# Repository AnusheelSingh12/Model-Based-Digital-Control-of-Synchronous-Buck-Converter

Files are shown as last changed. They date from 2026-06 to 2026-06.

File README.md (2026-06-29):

# Model-Based Design and HIL Deployment of a Cascade Digital Controller for a Synchronous Buck Converter on TI C2000 DSP

## Summer Research Internship

**Institution:** Indian Institute of Technology Guwahati

**Duration:** May 2026 – July 2026

---

# Overview

This repository documents my Summer Research Internship carried out at the Department of Electronics and Electrical Engineering, Indian Institute of Technology Guwahati.

The internship focused on the complete workflow involved in designing, simulating, implementing, and validating a digitally controlled synchronous buck converter using the Texas Instruments C2000 real-time digital signal processor platform.

Unlike repositories that present only the final implementation, this repository documents the complete engineering process, beginning with mathematical modeling and simulation, progressing through controller design, embedded firmware development, peripheral configuration, laboratory validation, and finally hardware deployment.

The project combines concepts from:

* Power Electronics
* Control Systems
* Embedded Systems
* Digital Signal Processing
* MATLAB & Simulink
* Simscape Electrical
* Real-Time Embedded Programming
* Hardware-in-the-Loop Development

---

# Project Objectives

The primary objectives of the internship were:

* Develop a high-fidelity digital twin of a synchronous buck converter.
* Design a cascaded digital controller consisting of outer voltage and inner current control loops.
* Learn the Texas Instruments C2000 development ecosystem.
* Implement embedded firmware using Code Composer Studio.
* Configure and validate DSP peripherals including GPIO, Timers, PWM, Interrupts, and ADC.
* Validate controller performance using laboratory instruments.
* Document the complete engineering workflow.

---

# Engineering Workflow

```text
Problem Definition
        │
        ▼
MATLAB Fundamentals
        │
        ▼
Simulink Fundamentals
        │
        ▼
Simscape Electrical
        │
        ▼
Digital Twin Development
        │
        ▼
Cascade PI Controller Design
        │
        ▼
Closed Loop Simulation
        │
        ▼
TI C2000 DSP Learning
        │
        ▼
GPIO
Interrupts
CPU Timers
PWM
ADC
        │
        ▼
Hardware Validation
        │
        ▼
Final System Integration
```

---

# Repository Structure

```text
IITG-DSP-Buck-Converter-Control/

├── 01_Internship_Overview/
│
├── 02_MATLAB_and_Simulink/
│
├── 03_Digital_Twin/
│
├── 04_Cascade_Controller/
│
├── 05_TI_C2000_DSP/
│   ├── GPIO/
│   ├── Interrupts/
│   ├── CPU_Timers/
│   ├── ePWM/
│   ├── ADC/
│
├── 06_Hardware_Setup/
│   ├── LaunchXL_F28379D/
│   ├── Oscilloscope/
│   ├── Function_Generator/
│
├── 07_Firmware/
│
├── 08_Simulation_Results/
│
├── 09_Final_Report/
│
├── Images/
│
├── Videos/
│
└── README.md
```

---

# Project Phases

## Phase 1 — Digital Twin Development

The first stage of the project focused on constructing a high-fidelity Simscape Electrical model of the synchronous buck converter.

Topics include:

* Converter topology
* MOSFET modelling
* Passive component modelling
* PWM generation
* Open-loop validation
* Converter analysis
* Duty-cycle experiments

---

## Phase 2 — Cascade Digital Controller

The second stage involved designing a cascaded digital controller.

Topics include:

* Voltage control loop
* Current control loop
* PI controller design
* Closed-loop regulation
* Controller tuning
* Performance analysis

---

## Phase 3 — TI C2000 DSP Development

The third stage focused on learning and implementing embedded firmware using the Texas Instruments C2000 platform.

Topics include:

* Code Composer Studio
* Project configuration
* GPIO
* Interrupts
* CPU Timers
* Enhanced PWM
* ADC
* Debugging
* Flash programming

---

## Phase 4 — Hardware Validation

The final stage focuses on validating both the firmware and control algorithms using laboratory equipment.

Topics include:

* Oscilloscope measurements
* Function generator experiments
* PWM verification
* ADC verification
* Peripheral testing
* System integration

---

# Software and Development Tools

MATLAB

Simulink

Simscape Electrical

Code Composer Studio

C2000Ware

Texas Instruments C2000 Driver Library

---

# Hardware Platform

Texas Instruments LaunchXL-F28379D

Texas Instruments C2000 DSP

Rigol Digital Oscilloscope

Function Generator

Host Computer

---

# Skills Developed

Throughout this internship I gained practical experience in:

* Model-Based Design
* Power Electronics
* Control Systems
* Digital Signal Processing
* MATLAB Programming
* Simulink Modelling
* Simscape Electrical
* Embedded C Programming
* TI C2000 Development
* Code Composer Studio
* GPIO Configuration
* Interrupt Programming
* CPU Timers
* PWM Generation
* ADC Configuration
* Oscilloscope Measurements
* Function Generator Operation
* Hardware Debugging
* Engineering Documentation

---

# Repository Navigation

| Section | Description |
| --- | --- |
| Internship Overview | Internship objectives, timeline, and research scope |
| MATLAB and Simulink | Learning material and simulation fundamentals |
| Digital Twin | Simscape converter modelling |
| Cascade Controller  | Controller design and closed-loop simulation |
| TI C2000 DSP | Embedded firmware development |
| Hardware Setup | Laboratory setup and instrumentation |
| Firmware | Embedded source code |
| Simulation Results  | Waveforms and experimental validation |
| Final Report | Internship report and documentation |

---

# Current Status

The repository is actively maintained and will continue to be updated throughout the internship.

Future updates include:

* Complete firmware
* Hardware validation
* Oscilloscope measurements
* ADC experiments
* Closed-loop implementation
* Final internship report
* Demonstration videos

---

# Acknowledgements

I would like to express my sincere gratitude to my internship supervisor, research mentors, and the School of Electronics and Electrical Engineering at the Indian Institute of Technology Guwahati for providing the opportunity to work on this project and gain practical experience in model-based design, embedded control systems, and real-time digital signal processing.

---

# Author

Anusheel Singh

Electronics and Communication Engineering

Areas of Interest

* Embedded Systems
* Digital Control Systems
* Power Electronics
* DSP
* Hardware Integration
* Robotics
* Automotive Electronics

---

This repository is intended to serve as a complete technical record of my internship, documenting both the engineering process and the final implementation.

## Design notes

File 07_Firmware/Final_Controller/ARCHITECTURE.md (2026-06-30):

# Synchronous Buck Converter — Firmware Architecture Guide
## TI LaunchXL-F28379D | Cascaded PI Control | 100kHz

---

## 1. File Structure

```
buck_converter/
├── src/
│   ├── main.c          → System init, startup sequence
│   ├── epwm.c          → PWM generation, duty cycle update
│   ├── adc.c           → ADC configuration, scaling constants
│   ├── controller.c    → PI controller math, anti-windup
│   └── interrupts.c    → ADC ISR, complete control loop
├── include/
│   ├── epwm.h          → PWM defines, function prototypes
│   ├── adc.h           → ADC channel assigns, scaling, globals
│   ├── controller.h    → PI struct, gains, prototypes
│   └── interrupts.h    → ISR prototype
└── ARCHITECTURE.md     → This file
```

---

## 2. Control Flow

```
EPWM1 Counter = 0 (every 10us)
        ↓
SOCA Trigger → ADCA + ADCB sample simultaneously
        ↓
ADC Conversion (~300ns)
        ↓
ADCINT1 fires → ADC_ISR enters
        ↓
Read Vout raw, Iout raw
        ↓
Scale to V and A
        ↓
Voltage PI: error_v = Vref - Vout → Iref
        ↓
Current PI: error_i = Iref - Iout → duty
        ↓
EPWM_setDutyCycle(duty) → CMPA shadow register
        ↓
Clear ADCINT1 flag + PIE ACK Group 1
        ↓
ISR exits → CPU idle until next cycle
        ↓
Next counter zero: shadow CMPA → active CMPA
```

---

## 3. Simulink to Firmware Mapping

| Simulink Block | Firmware Location |
|---|---|
| ADC (Vout channel) | `adc.c` ADCA SOC0 |
| ADC (Iout channel) | `adc.c` ADCB SOC0 |
| ADC Scaling gain | `g_vOut = raw * VOLTAGE_SCALE` |
| Voltage reference (12V) | `g_vref = VREF` in controller.h|
| Voltage PI block | `PI_update(&voltagePI, ...)` |
| Current PI block | `PI_update(&currentPI, ...)` |
| Anti-windup saturation | Integrator clamp in PI_update()|
| Duty cycle saturation | EPWM_setDutyCycle() clamp |
| PWM Generator | `epwm.c` EPWM1 AQ config |
| Sample Time (Ts = 10us) | EPWM SOCA trigger, 100kHz |

---

## 4. Key Register Reference

### ePWM Registers
| Register | Purpose | This Project |
|---|---|---|
| TBPRD | Sets switching frequency | 1000 → 100kHz |
| CMPA | Sets duty cycle | 50-950 (5%-95%) |
| TBCTL | Counter mode | Up-Down |
| AQCTLA | Output logic | HIGH up, LOW down |
| DBRED | Rising edge dead time | 20 counts = 100ns |
| DBFED | Falling edge dead time | 20 counts = 100ns |
| ETSEL | ADC trigger source | Counter zero |
| ETPS | Trigger prescale | Every cycle |

### ADC Registers
| Register | Purpose | This Project |
|---|---|---|
| ADCCTL2  | Clock prescaler | /4 = 50MHz |
| ADCSOC0CTL | Channel, trigger, window | ADCIN0, EPWM1SOCA, 15 cycles |
| ADCINTSEL | Interrupt source | SOC0 EOC |
| ADCRESULT0 | Conversion result | 0-4095 counts |

---

## 5. Watch Window Variables (Debug)

Add these to Expressions window in CCS:

| Variable | Description | Expected at 12V/1A |
|---|---|---|
| `g_vOut` | Measured output voltage (V) | ~12.0 |
| `g_iOut` | Measured output current (A) | ~1.0 |
| `g_vref` | Voltage reference (V) | 12.0 |
| `g_iref` | Current reference from Vloop | ~1.0 |
| `g_duty` | Duty cycle (normalized) | ~0.5 |
| `g_error_v` | Voltage error (V) | ~0.0 at steady state|
| `g_error_i` | Current error (A) | ~0.0 at steady state|
| `g_adcVoutRaw`| Raw ADC count (debug) | ~1858 |
| `g_adcIoutRaw`| Raw ADC count (debug) | ~varies with sensor|

---

## 6. PI Gain Tuning Procedure

### Step 1: Start Open Loop
Comment out the PI calls in interrupts.c and set fixed duty:
```c
g_duty = 0.5f;  // Fixed 50% for testing
EPWM_setDutyCycle(g_duty);
```
Verify Vout ≈ 12V on scope. Verify ADC reads correct value.

### Step 2: Tune Current Loop First (Inner)
Re-enable current PI only. Set Iref manually:
```c
g_iref = 1.0f;  // 1A reference, fixed
g_duty = PI_update(&currentPI, g_iref, g_iout);
```
Increase CURRENT_KP until current waveform oscillates. Back off 50%.
Then increase CURRENT_KI until steady state error is zero.

### Step 3: Tune Voltage Loop (Outer)
Re-enable both loops. Start with very small VOLTAGE_KP (0.01).
Increase until Vout responds quickly to step changes in Vref.
Add VOLTAGE_KI to eliminate steady-state error.

### Step 4: Verify on Scope
- CH1: EPWM1A (GPIO0) — 100kHz square wave
- CH2: Vout — steady 12V with small ripple
- CH3: Inductor current (if current probe available)

---

## 7. Expected Converter Parameters

```
Duty Cycle (D)    = Vout/Vin = 12/24 = 0.5 (50%)
Inductor Ripple   = Vin*D*(1-D) / (L*Fsw) = 24*0.5*0.5 / (50e-6*100e3) = 1.2A
Capacitor Ripple  = ΔIL / (8*C*Fsw) = 1.2 / (8*12.5e-6*100e3) = 120mV
Output Current    = Vout/Rload = 12/12 = 1A
```

These are your theoretical verification targets on the oscilloscope.

---

## 8. Hardware Connections

```
LaunchPad Pin    Signal         Connect To
─────────────────────────────────────────────
GPIO0 (J4 Pin2)  EPWM1A HS PWM  Gate driver IN+ (High Side)
GPIO1 (J4 Pin4)  EPWM1B LS PWM  Gate driver IN- (Low Side)
ADCINA0          Vout feedback  Resistor divider output
ADCINB0          Iout feedback  Current sensor output
GND              Ground         Shared GND with converter
3.3V             Vref           Current sensor supply
```

---

## 9. Safety Checklist Before Powering Converter

- [ ] Dead band verified on scope (no shoot-through)
- [ ] Duty cycle limits confirmed (5% min, 95% max)
- [ ] Current limit in voltage PI output (IREF_MAX = 2A)
- [ ] ADC scaling verified (g_vOut reads correct voltage)
- [ ] Both gate drive signals present on scope before connecting power
- [ ] Start with Vin = 5V, verify Vout, then increase to 24V

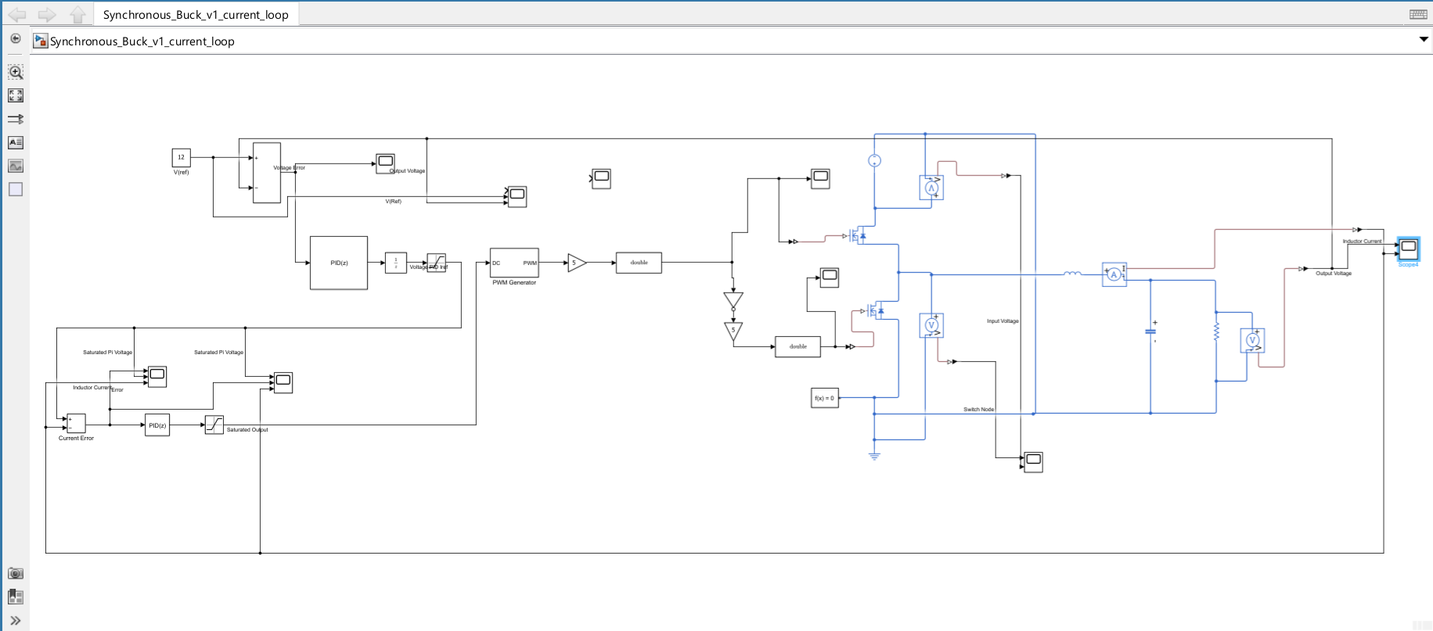
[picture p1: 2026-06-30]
02_MATLAB_Fundamentals/Images/Phase-2/Cascaded Control Architecture of Synchronous Buck Converter.png

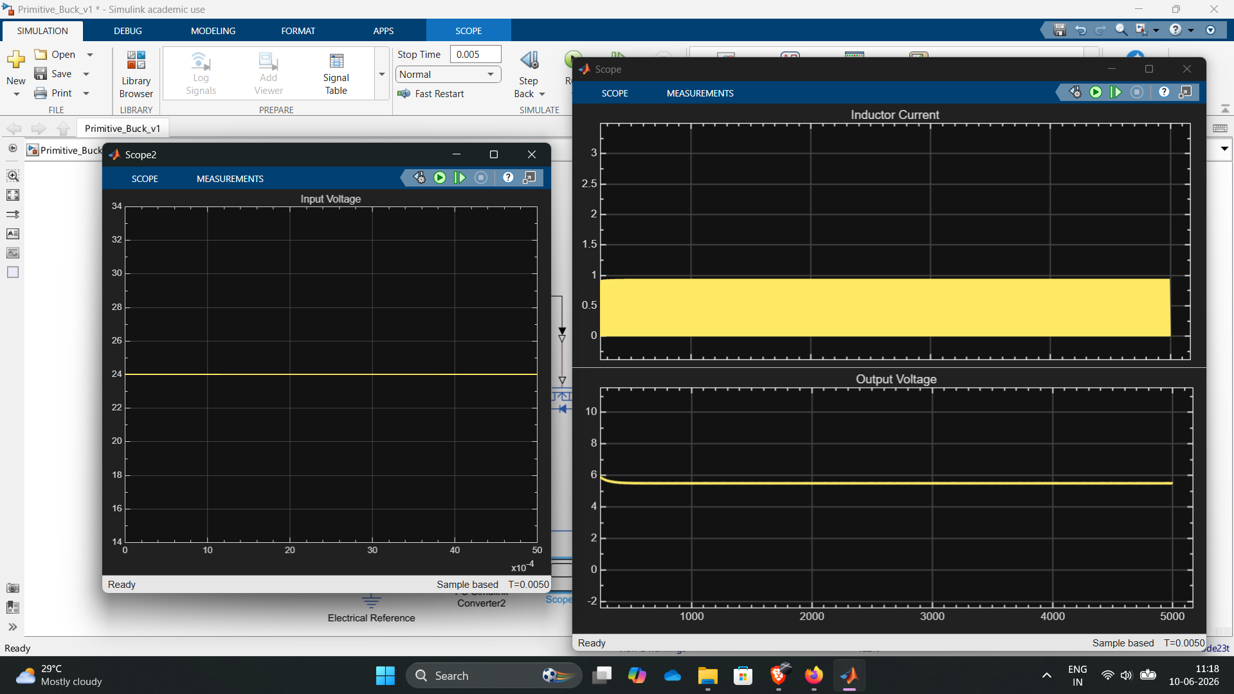
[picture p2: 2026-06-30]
03_Digital_Twin/Images/Primitive_Buck/25%_Duty_Cycle.png

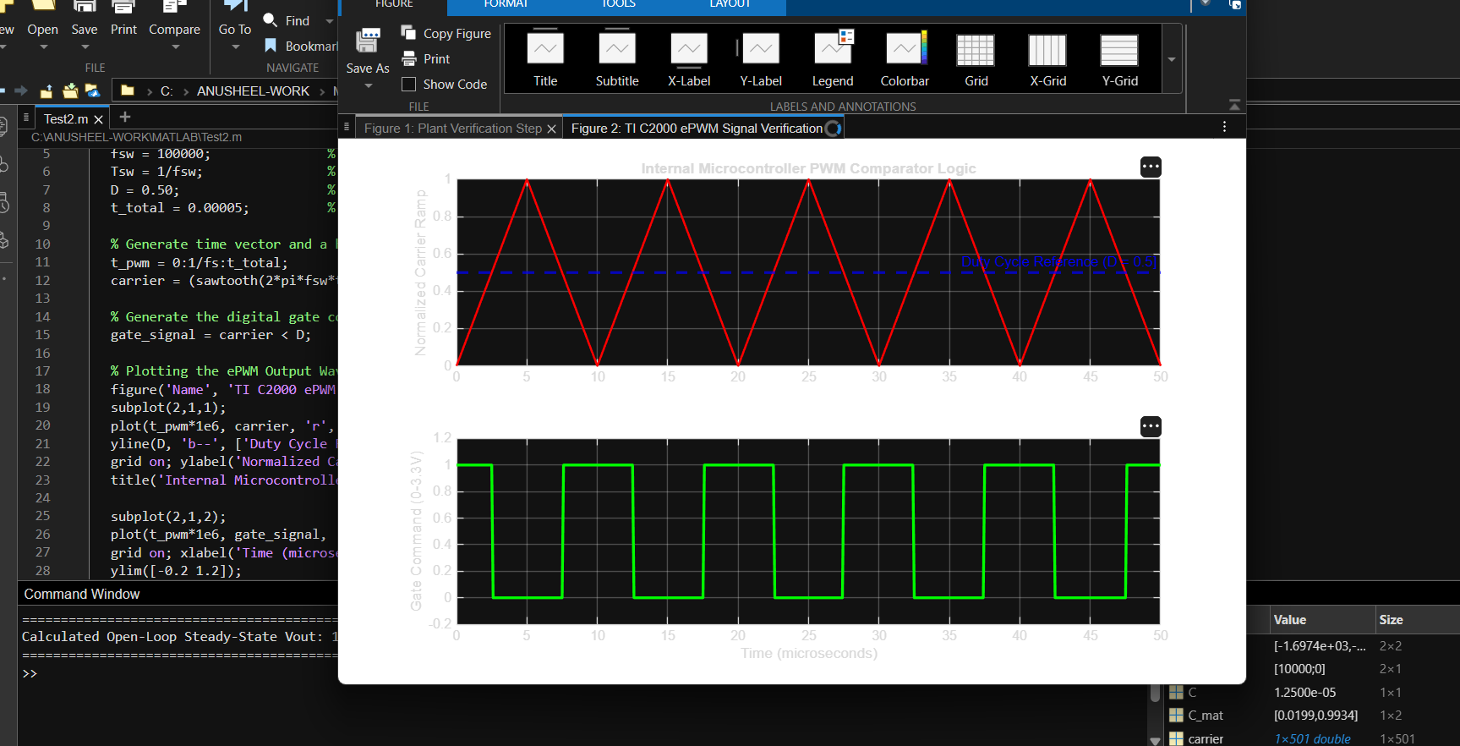
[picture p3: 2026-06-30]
02_MATLAB_Fundamentals/MATLAB/Images/Screenshot 2026-05-30 130607.png

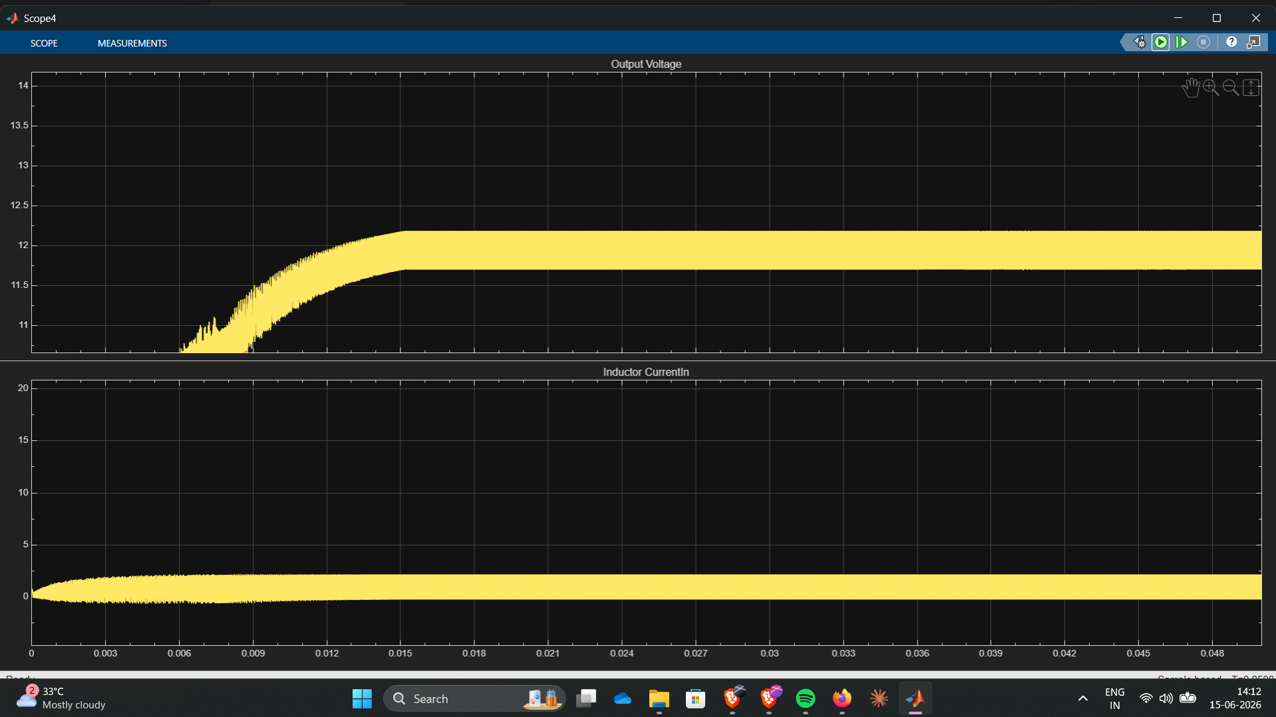
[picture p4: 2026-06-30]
02_MATLAB_Fundamentals/Images/Phase-2/Output_Voltage_Inductor_Current.png

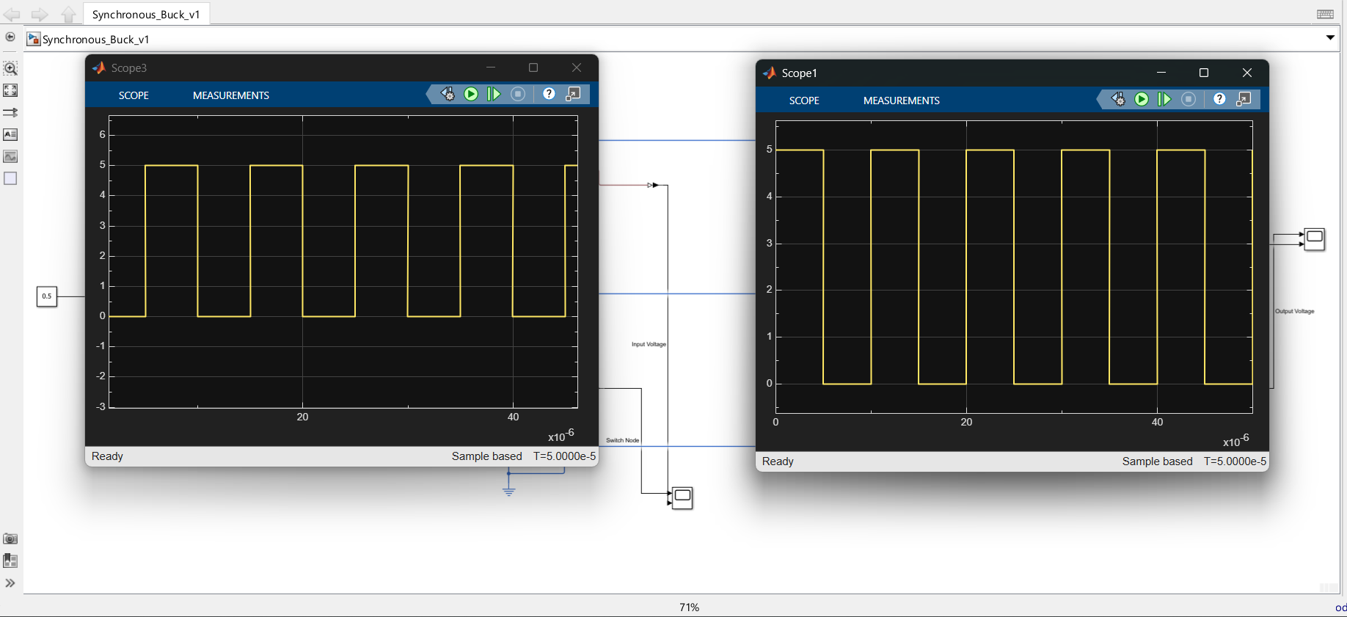
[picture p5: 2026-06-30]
03_Digital_Twin/Images/Synchronous_Buck/Input_PWM_Complementary_PWM.png

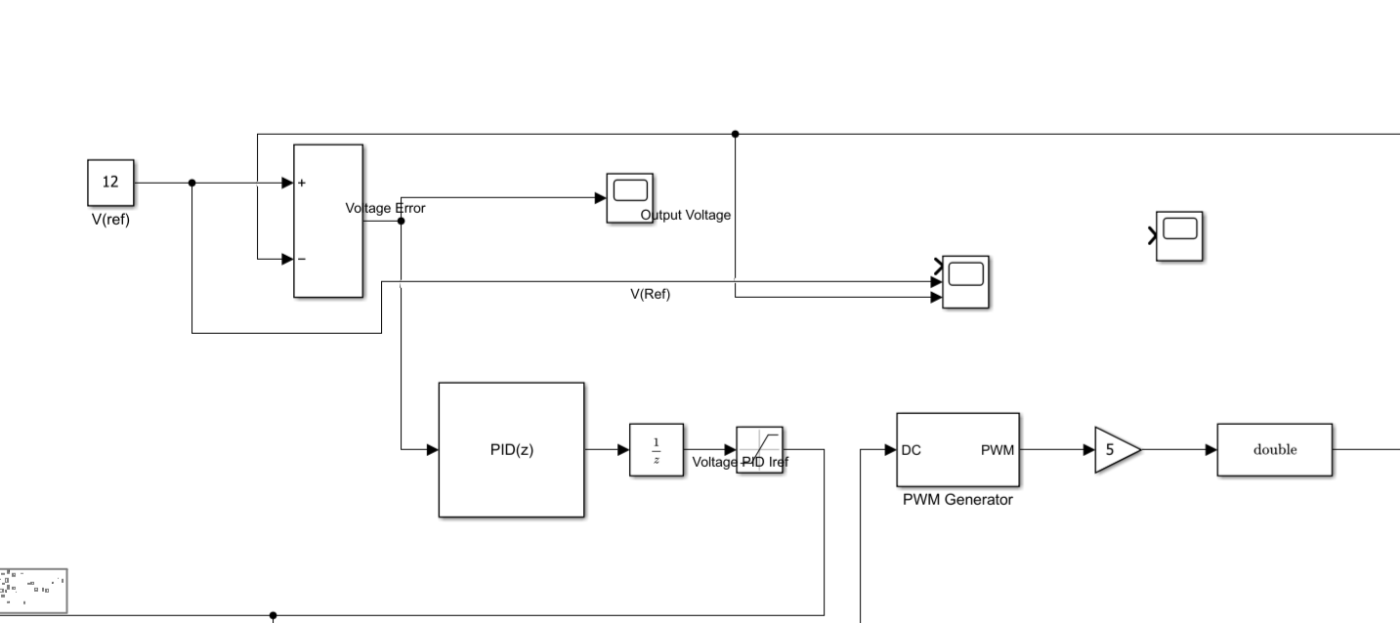
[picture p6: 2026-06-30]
02_MATLAB_Fundamentals/Images/Phase-2/Voltage_Loop.png

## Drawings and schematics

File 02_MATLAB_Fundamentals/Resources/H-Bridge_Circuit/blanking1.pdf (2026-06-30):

# 470pF ¹²kΩ

# IC10B 8 16 GND VCC IC10P

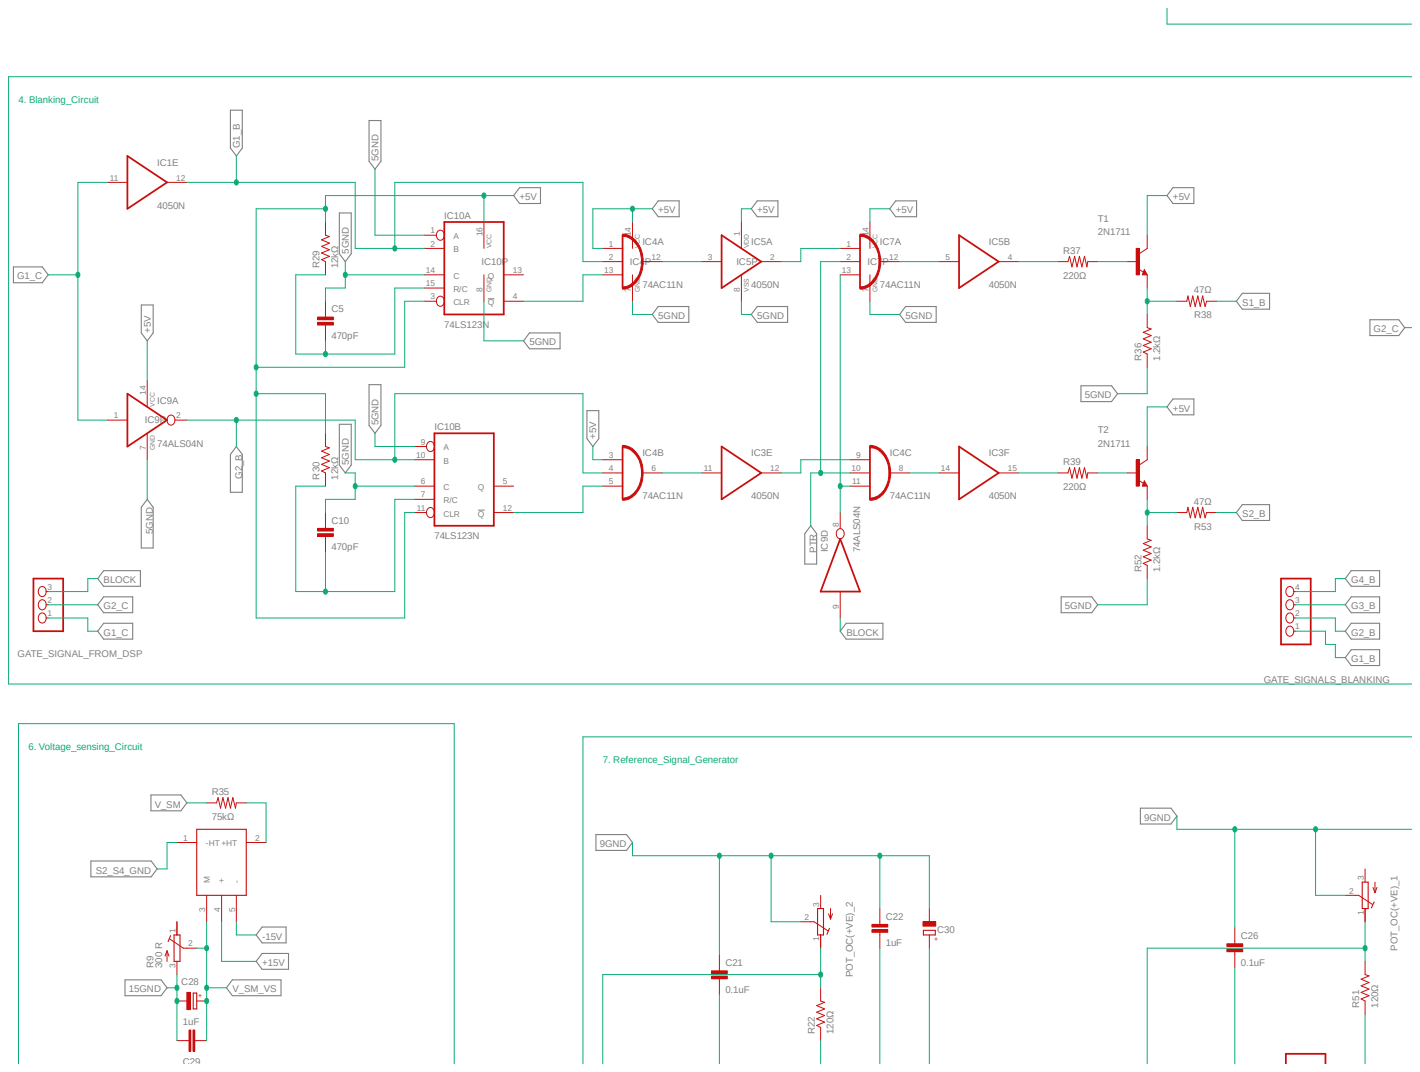
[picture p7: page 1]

IC7A 7 14 GND VCC IC7P 7 14 GND VCC IC4P

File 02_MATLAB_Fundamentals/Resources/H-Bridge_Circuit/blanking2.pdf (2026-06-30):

# 20-12-2025 12:21 C:\Users\eee\Desktop\SECL Materails\mmc_old.sch (Sheet: 1/1)

# 470pF ¹²kΩ

# IC12B 8 16 GND VCC IC12P

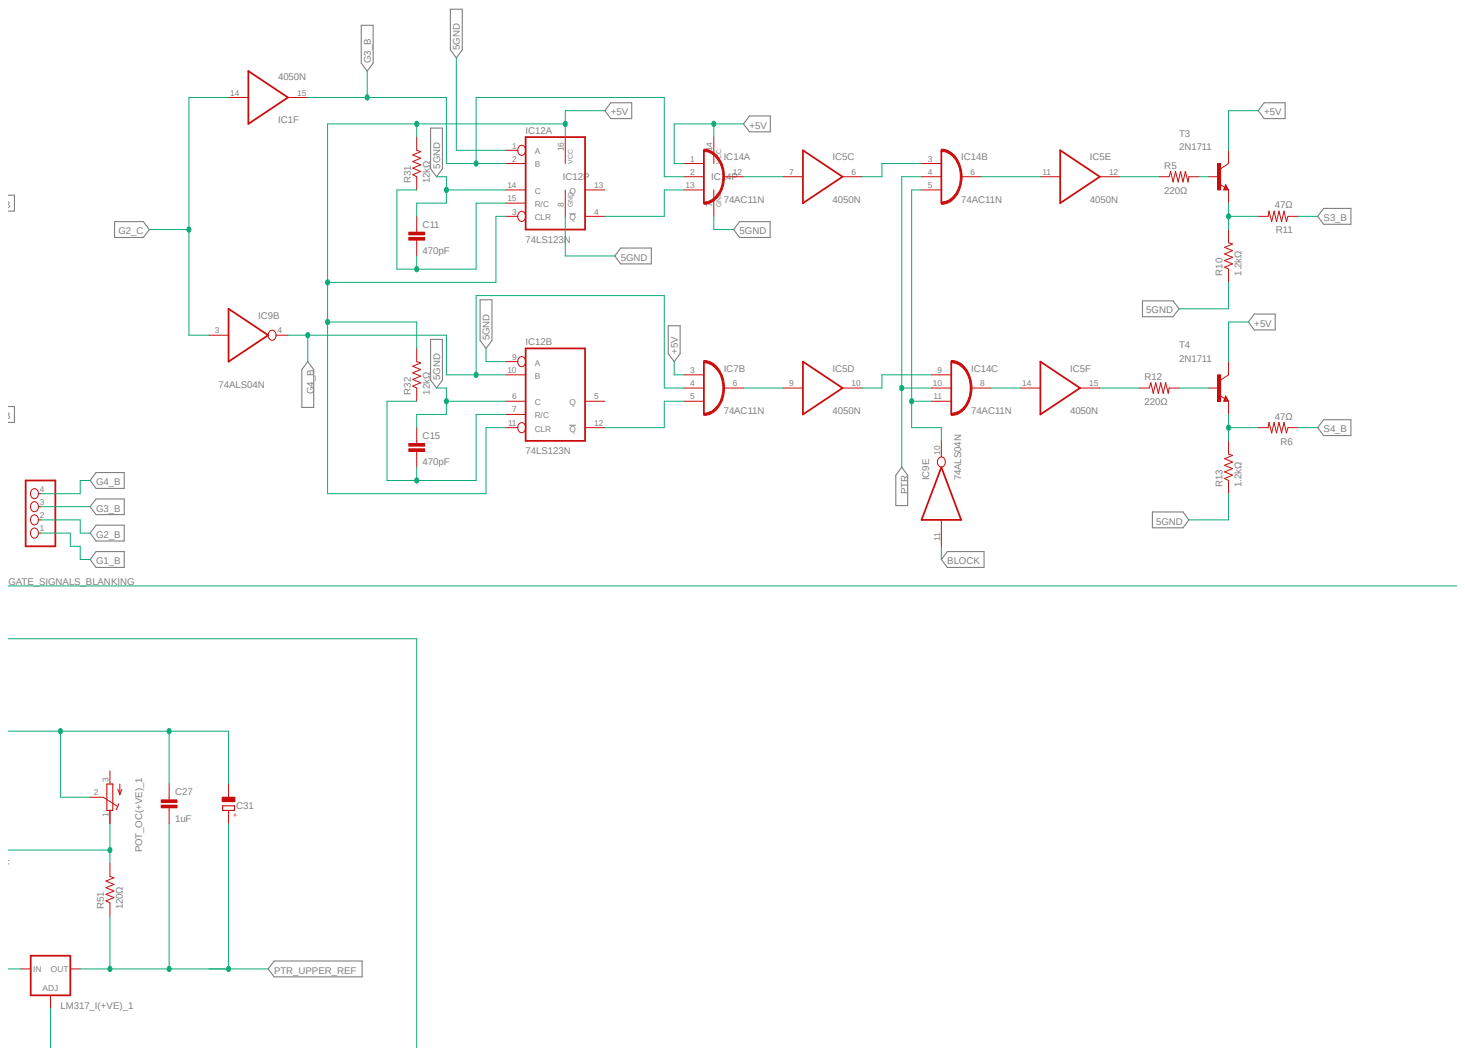
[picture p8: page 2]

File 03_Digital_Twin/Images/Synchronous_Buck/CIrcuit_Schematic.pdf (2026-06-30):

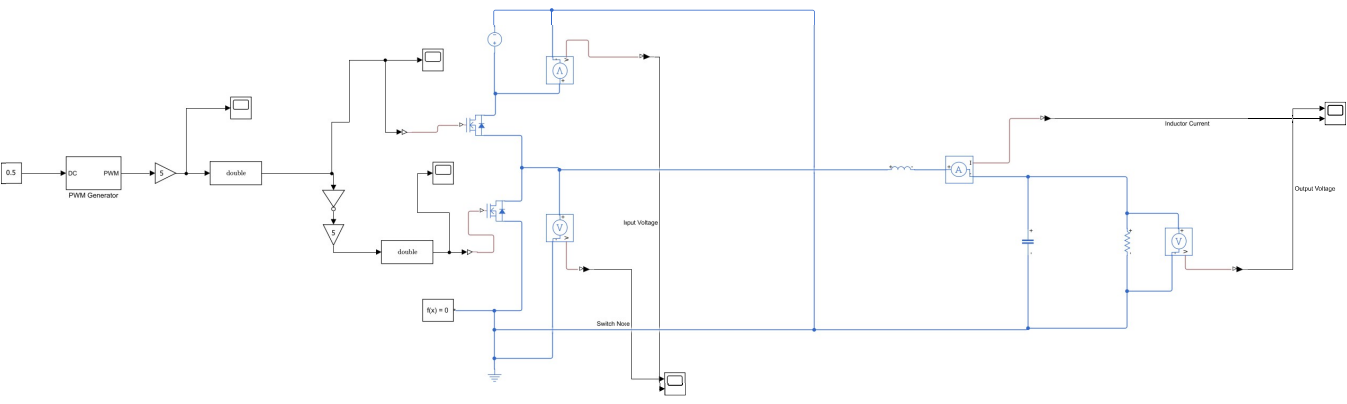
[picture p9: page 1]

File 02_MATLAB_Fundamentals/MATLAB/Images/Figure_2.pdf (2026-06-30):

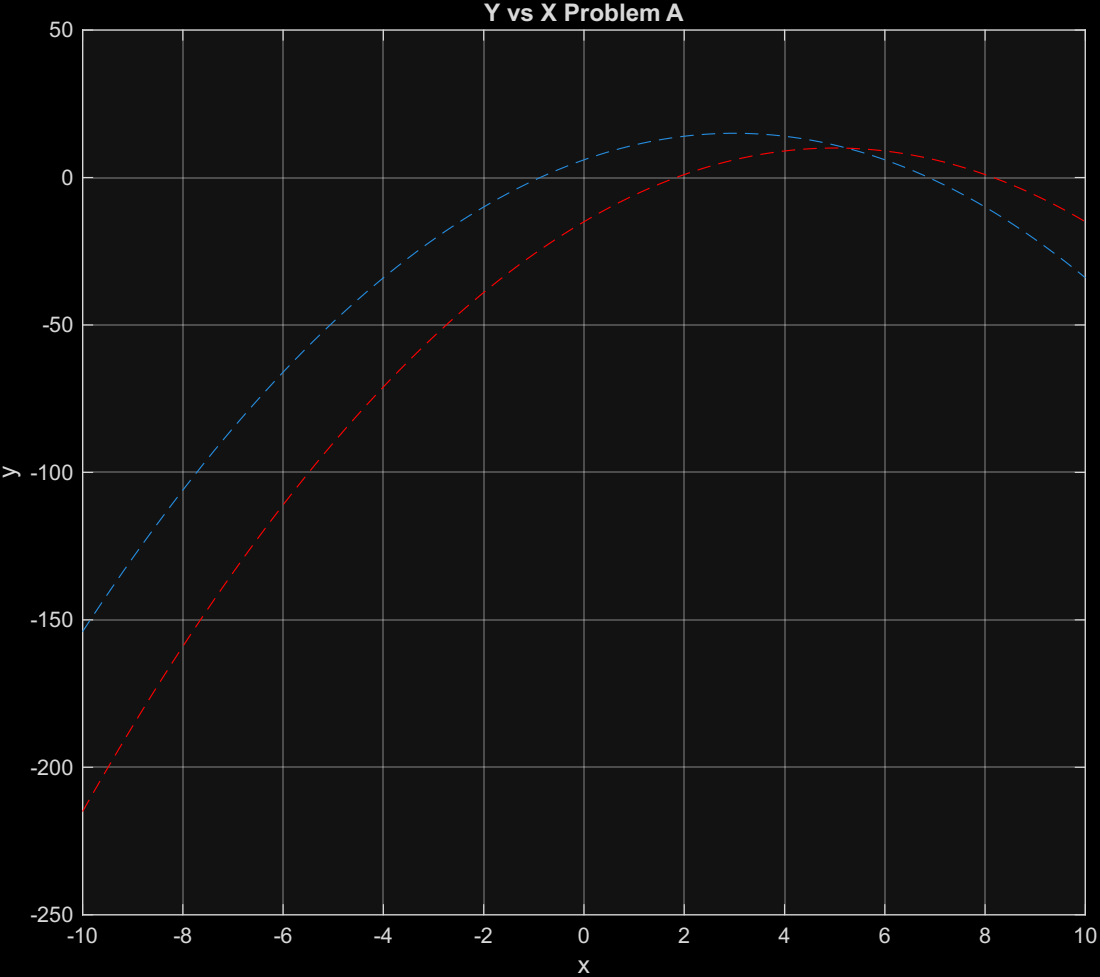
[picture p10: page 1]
Y vs X Problem A

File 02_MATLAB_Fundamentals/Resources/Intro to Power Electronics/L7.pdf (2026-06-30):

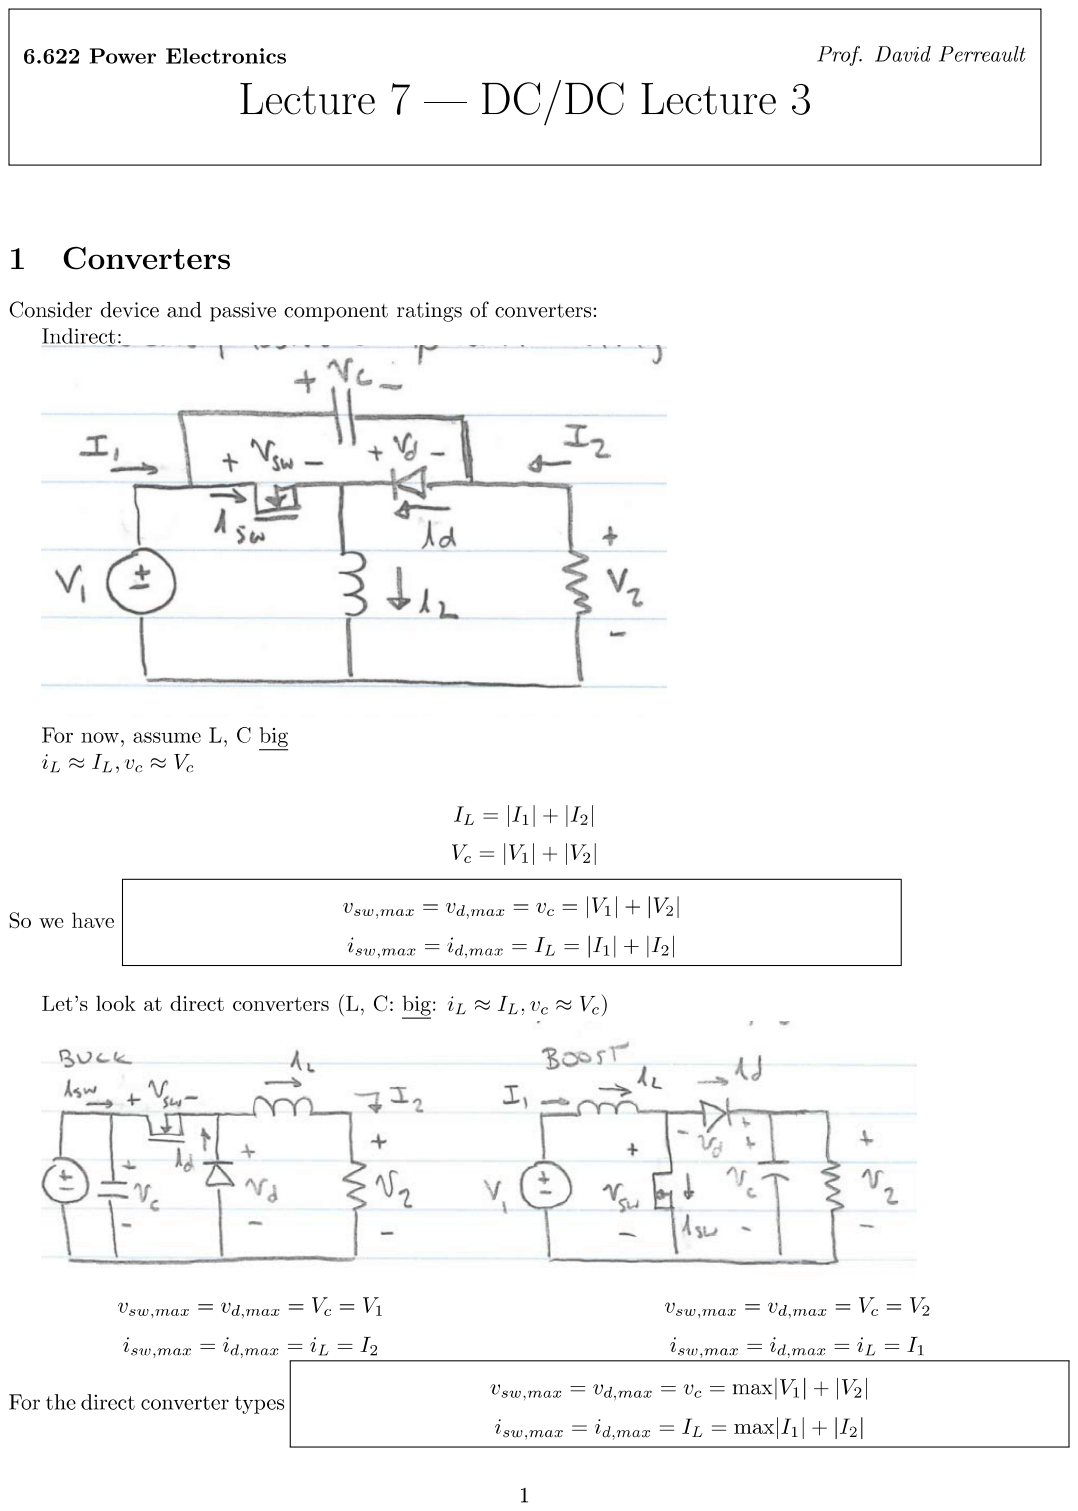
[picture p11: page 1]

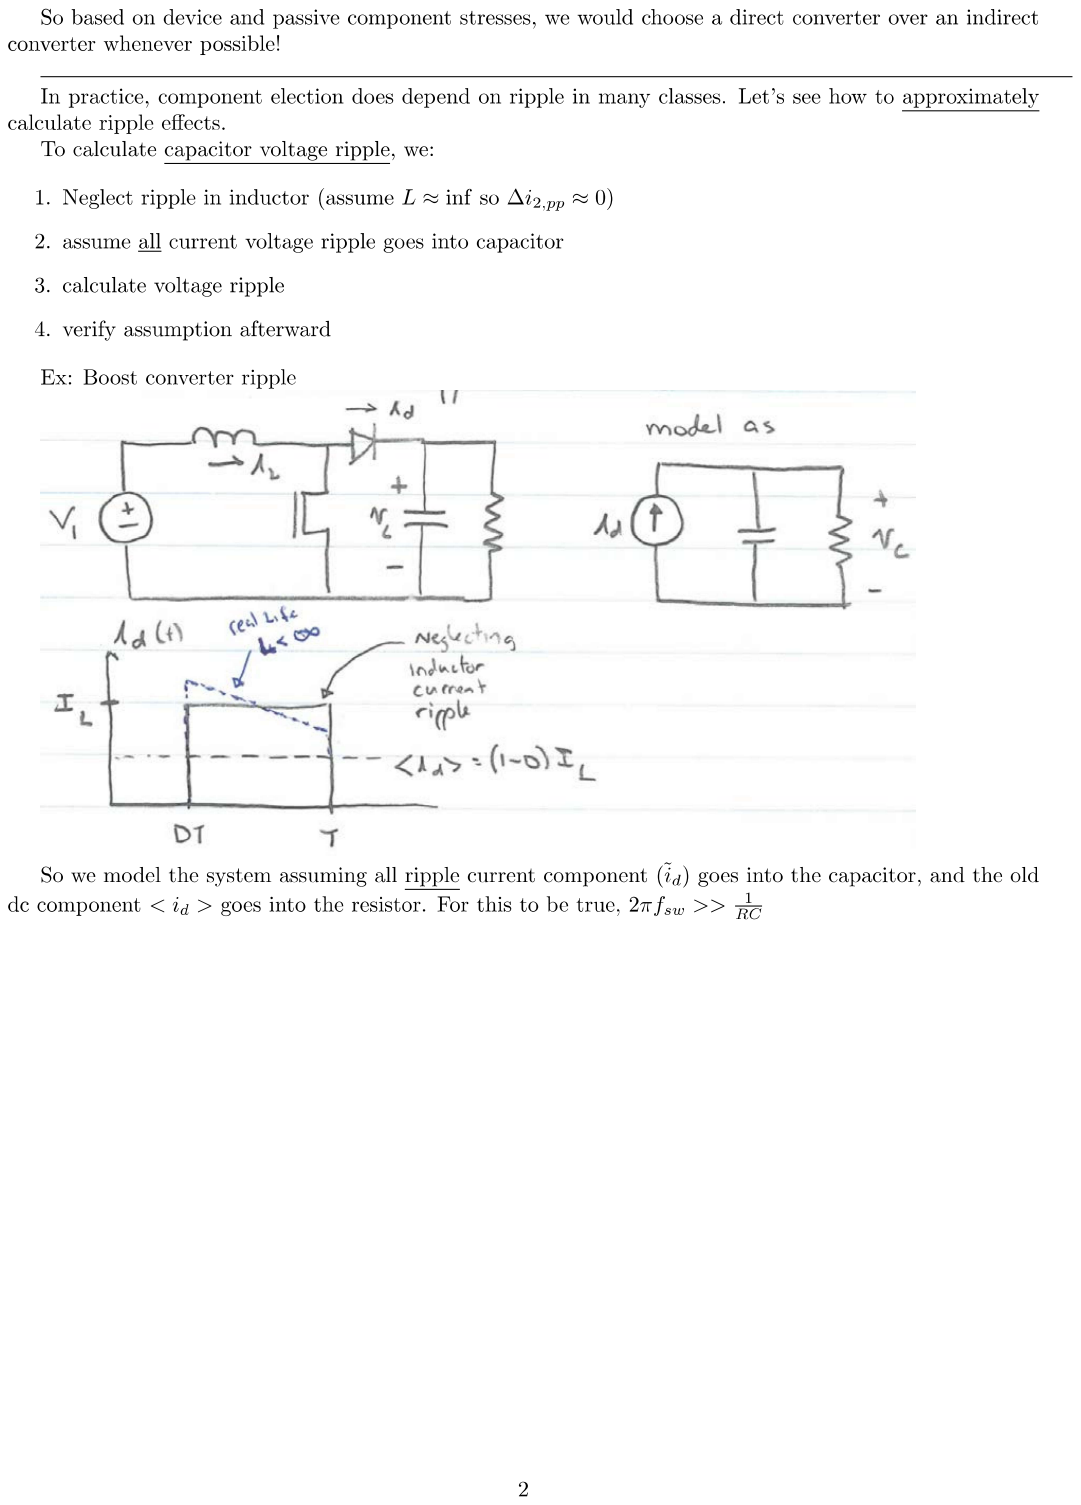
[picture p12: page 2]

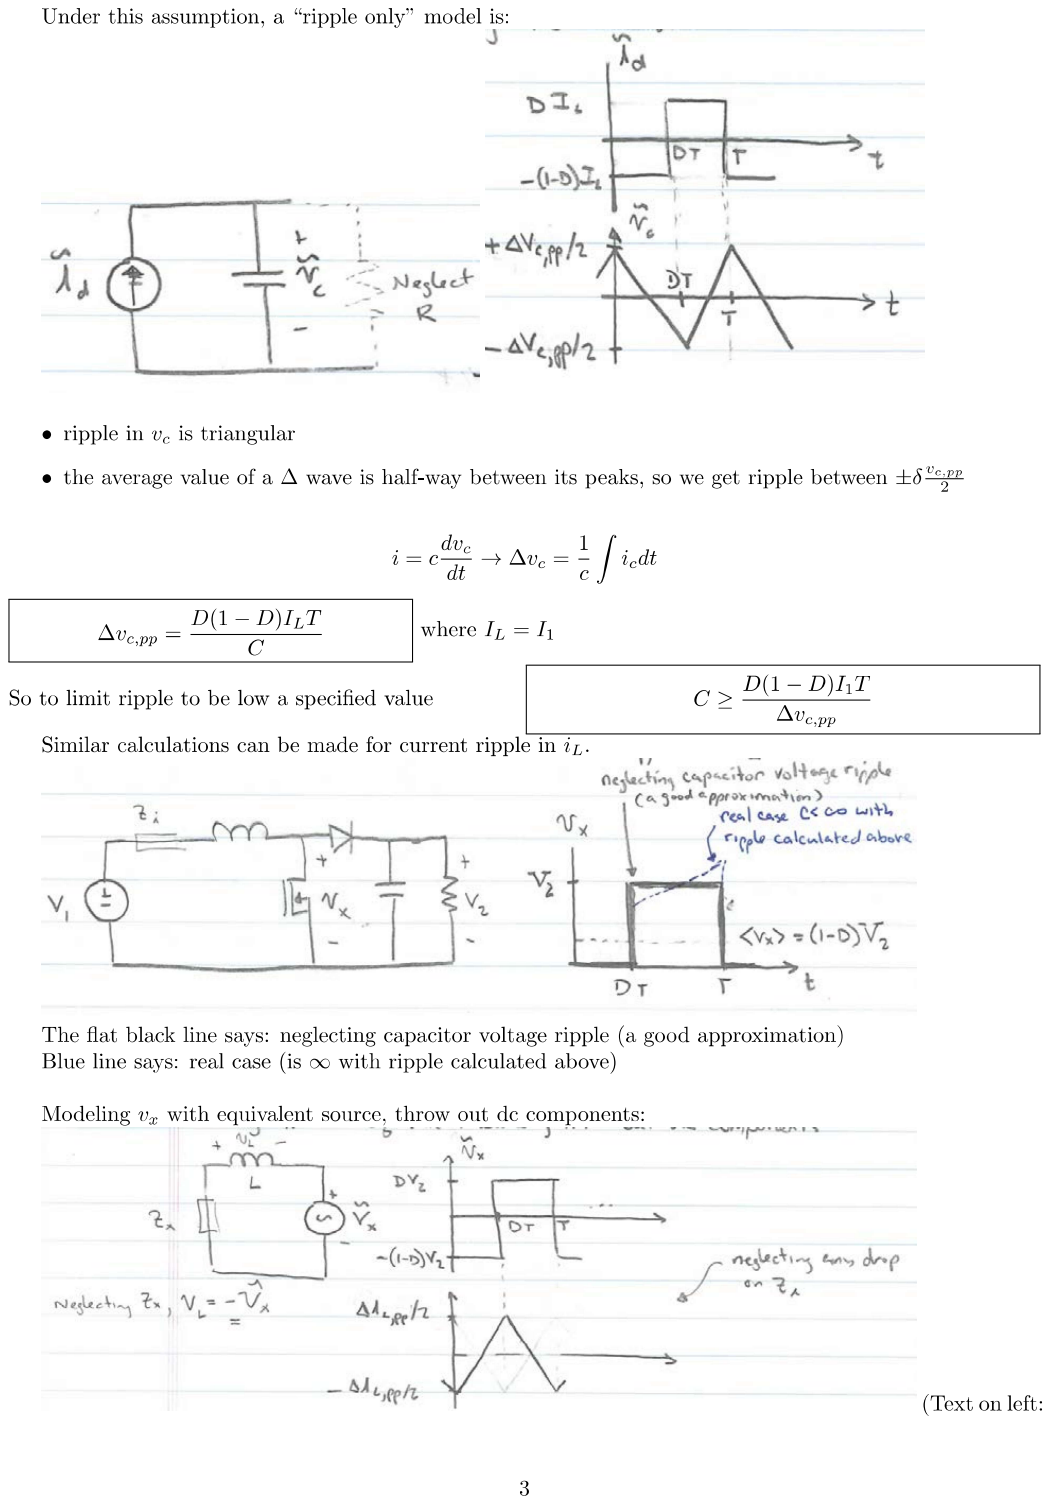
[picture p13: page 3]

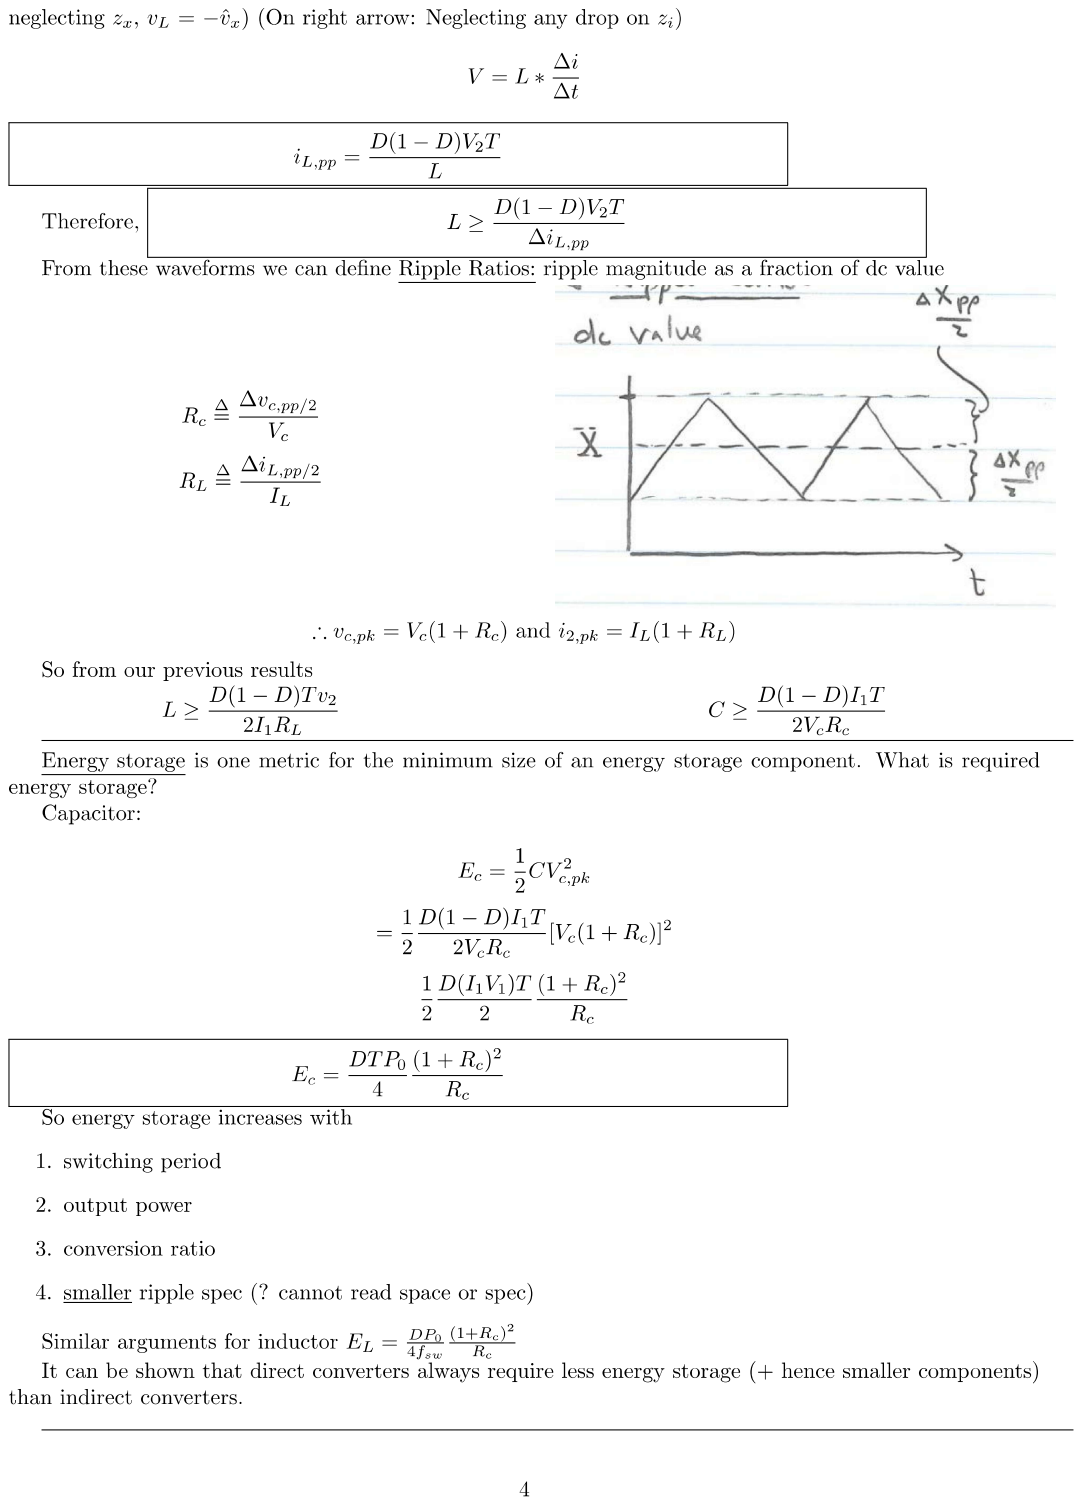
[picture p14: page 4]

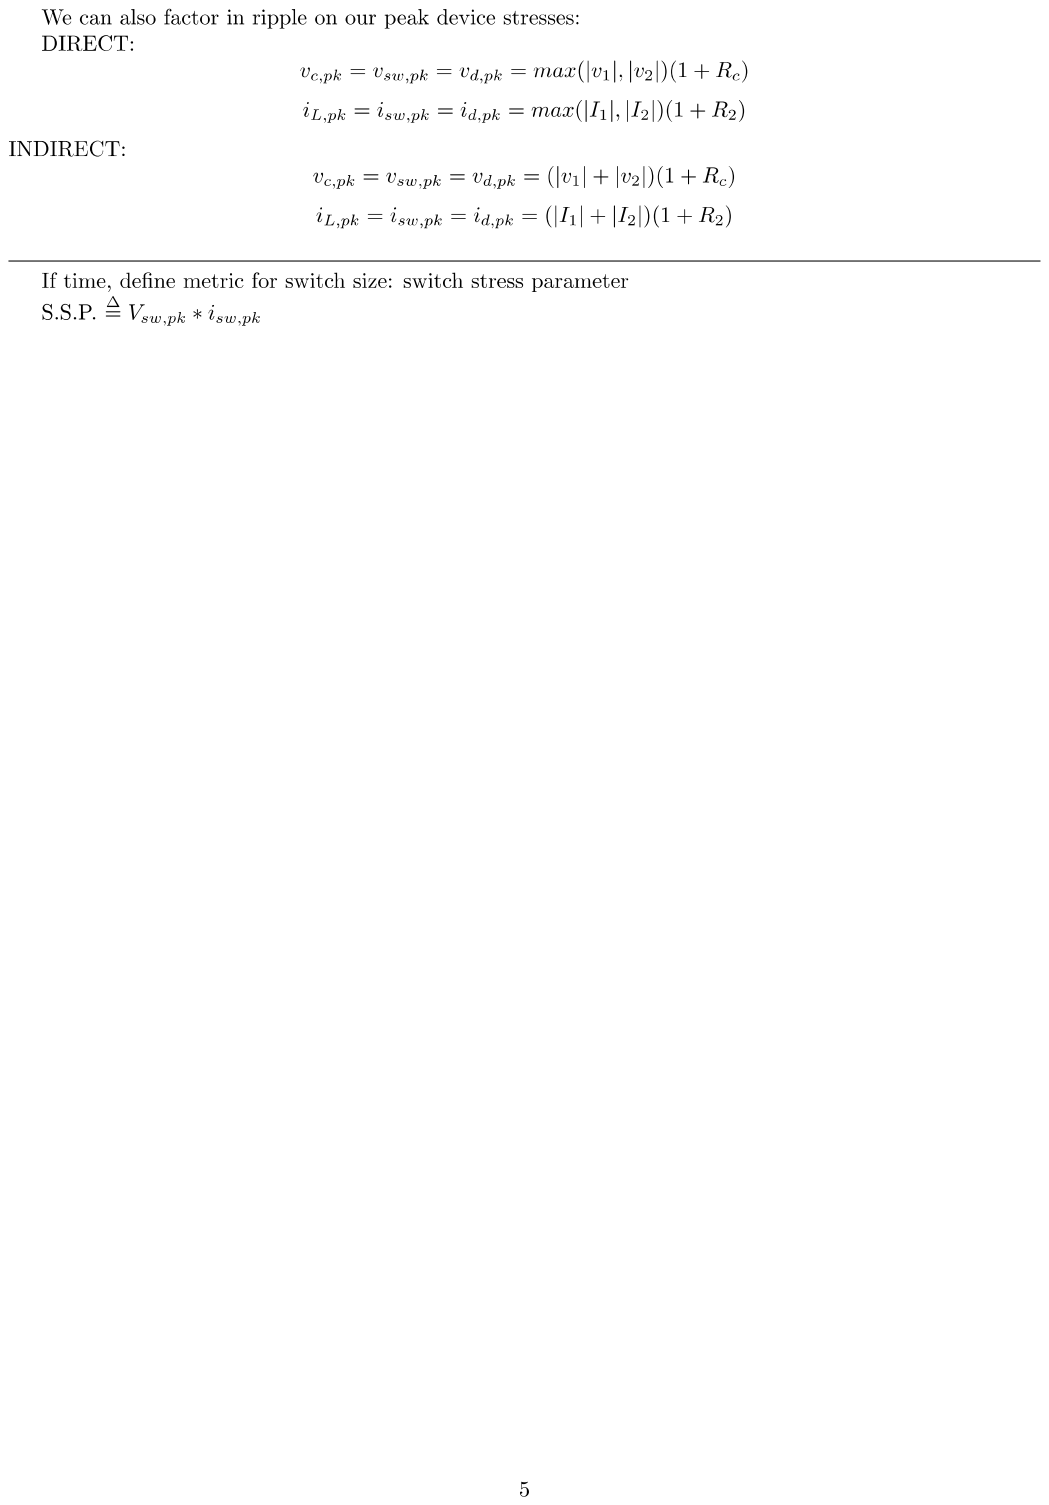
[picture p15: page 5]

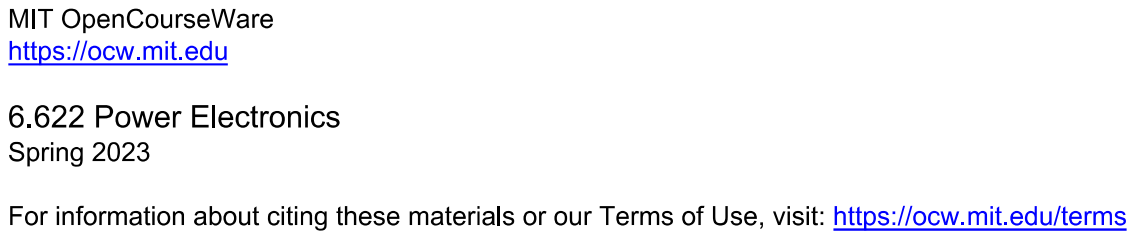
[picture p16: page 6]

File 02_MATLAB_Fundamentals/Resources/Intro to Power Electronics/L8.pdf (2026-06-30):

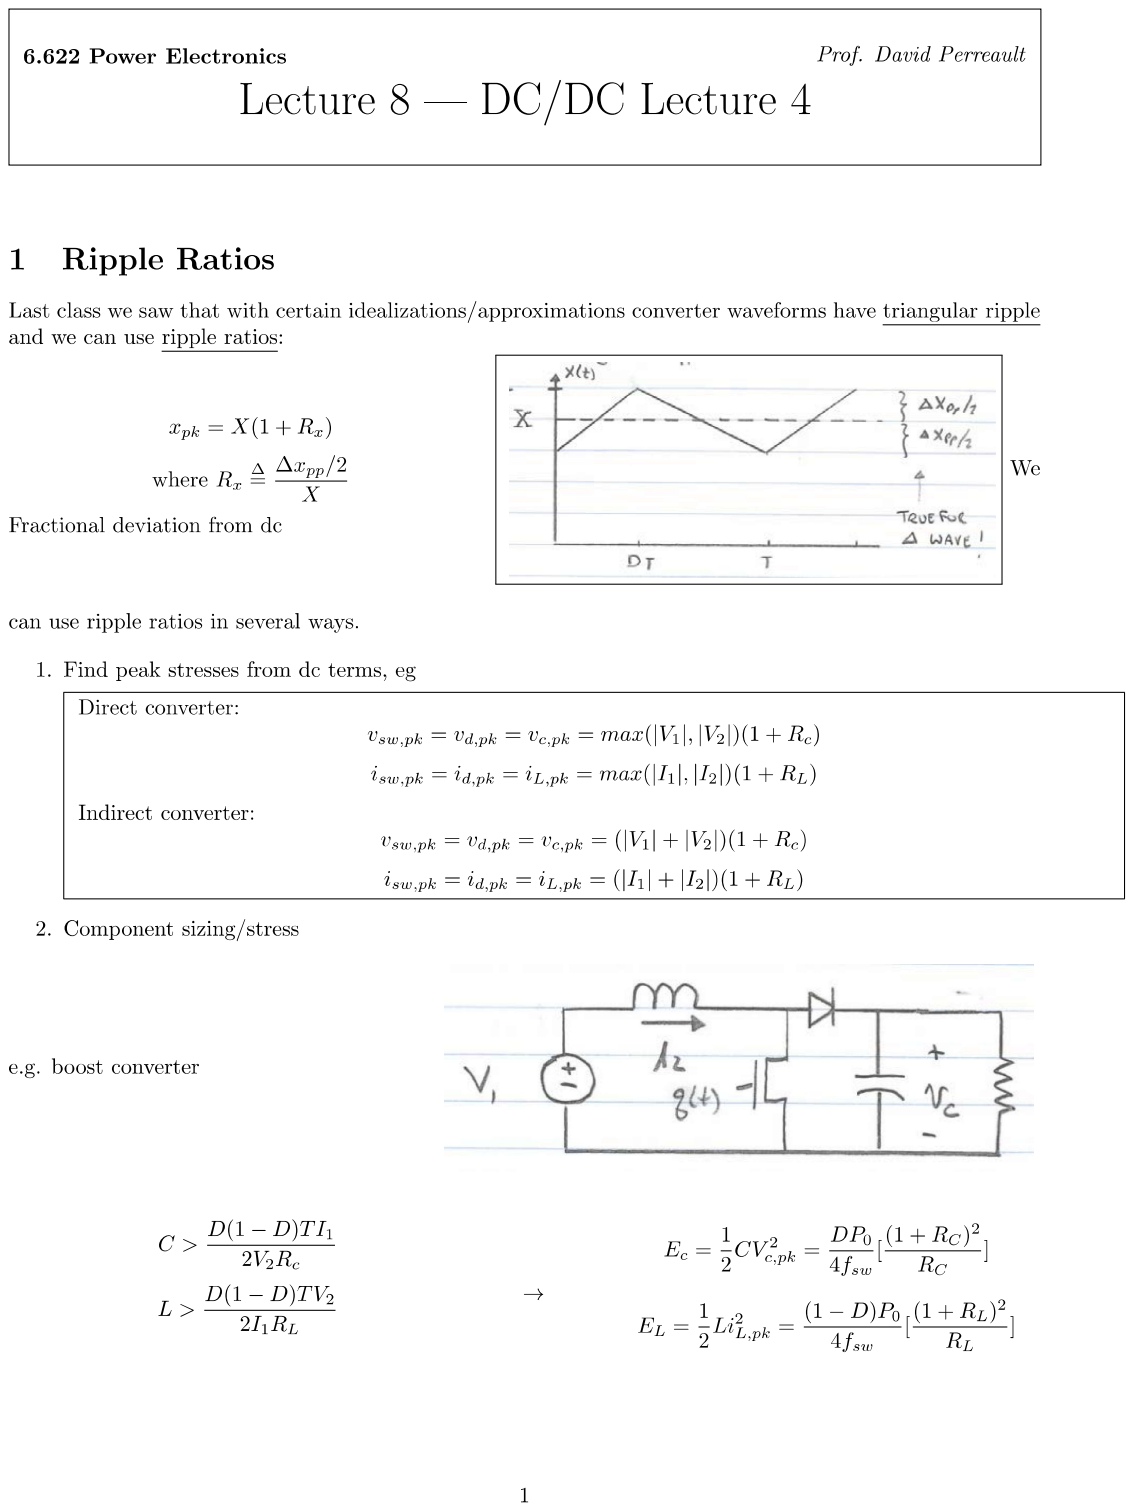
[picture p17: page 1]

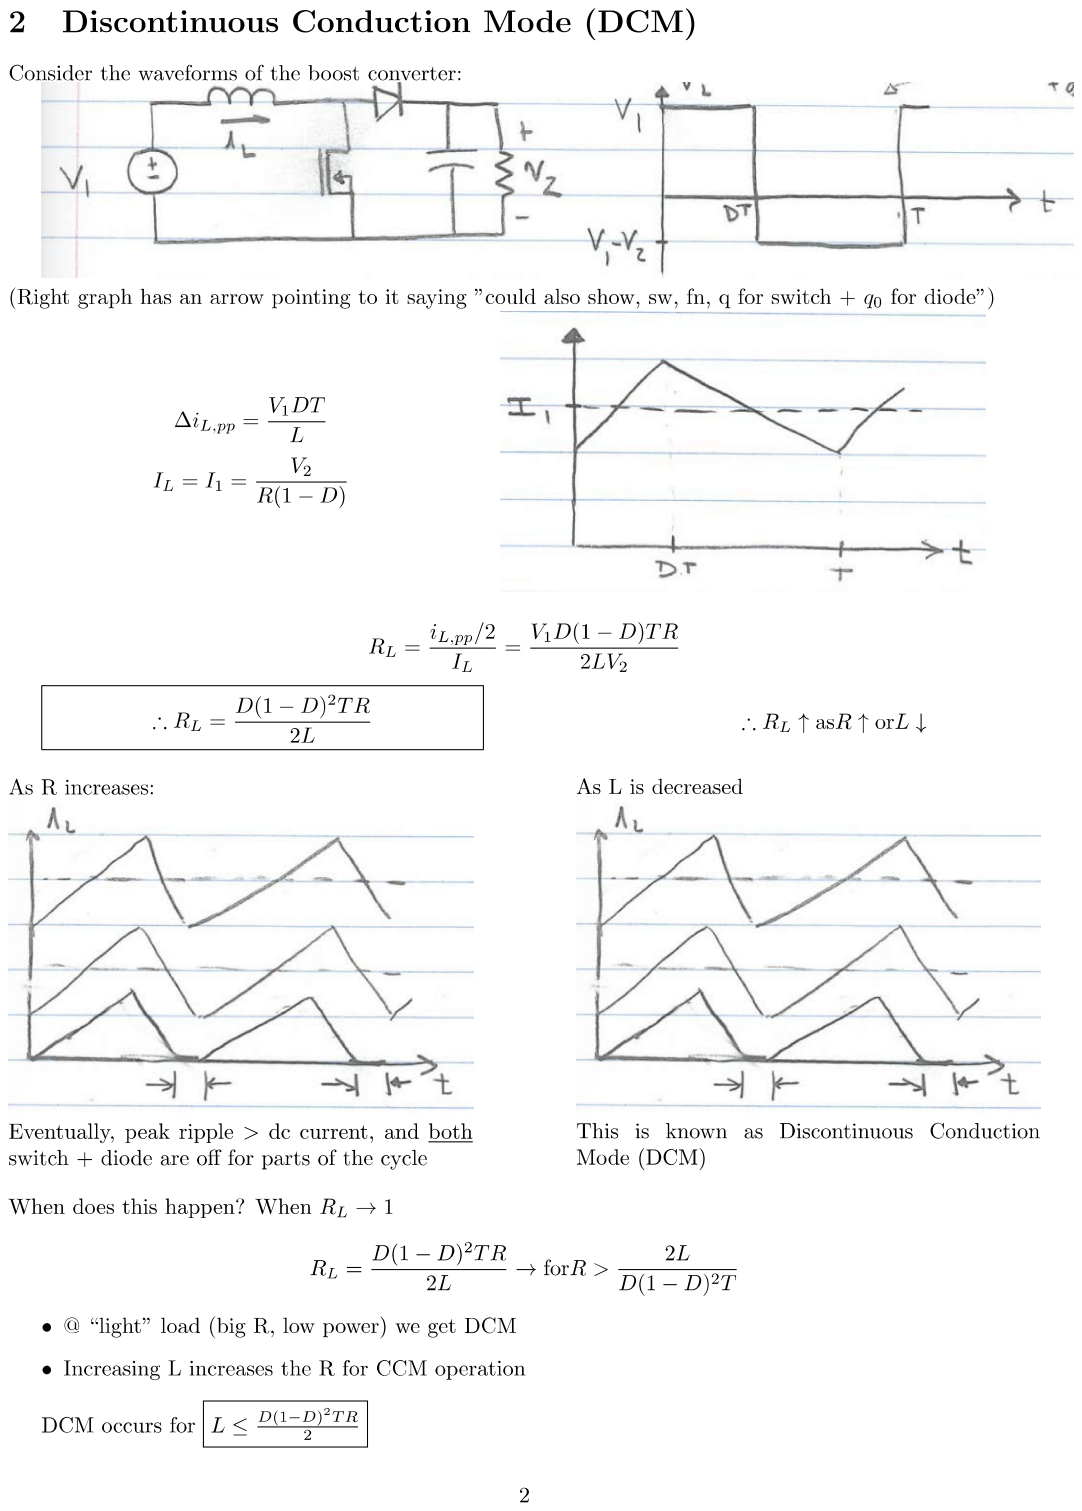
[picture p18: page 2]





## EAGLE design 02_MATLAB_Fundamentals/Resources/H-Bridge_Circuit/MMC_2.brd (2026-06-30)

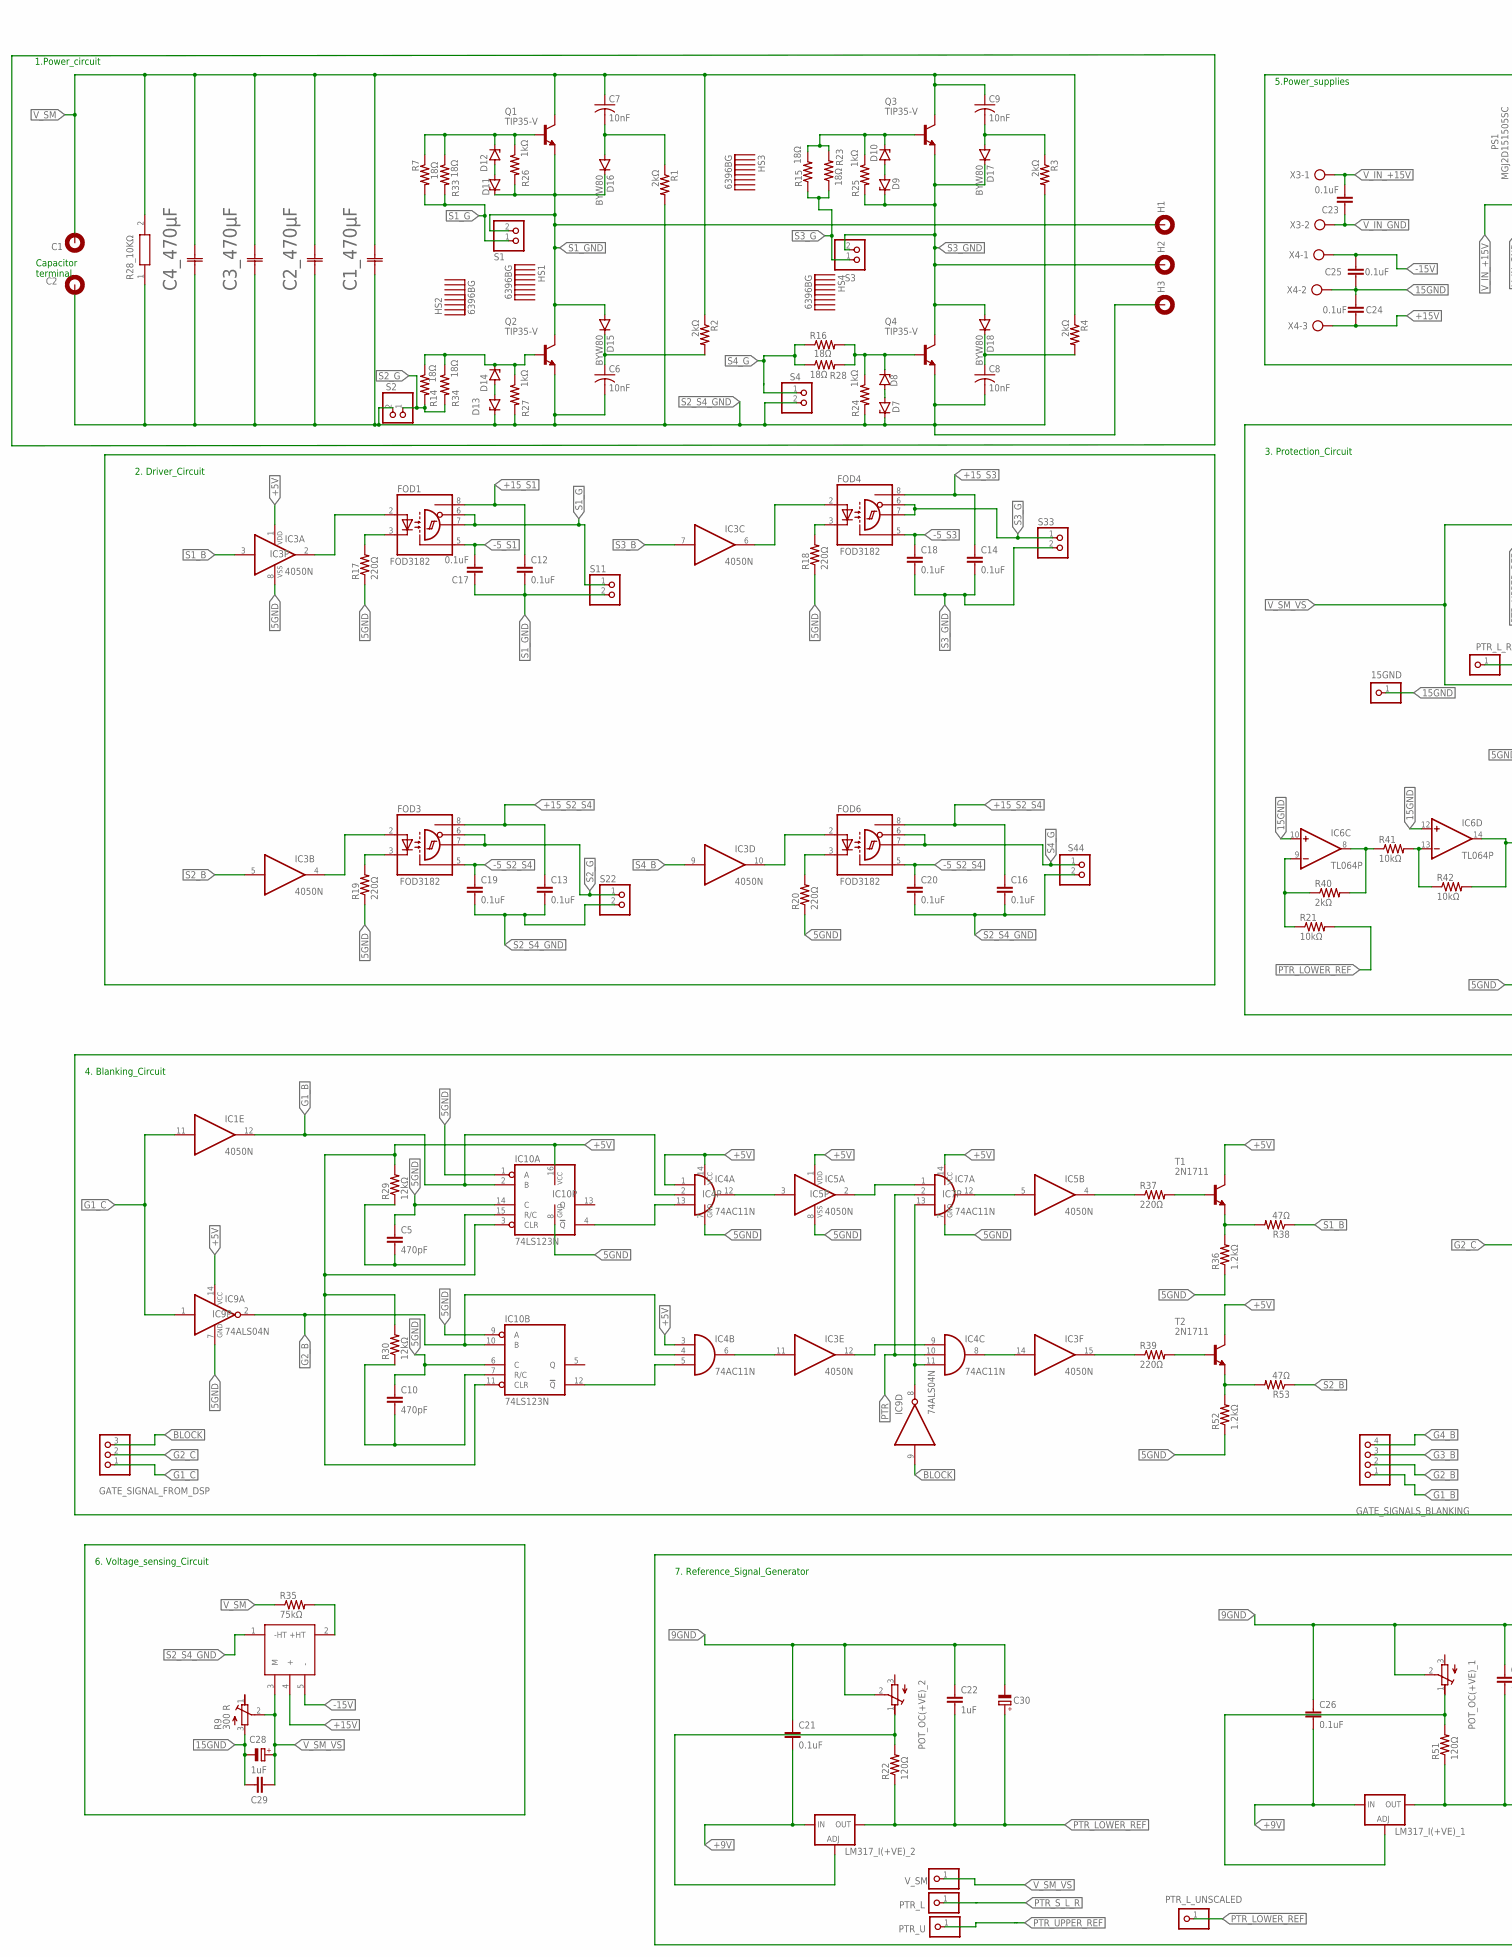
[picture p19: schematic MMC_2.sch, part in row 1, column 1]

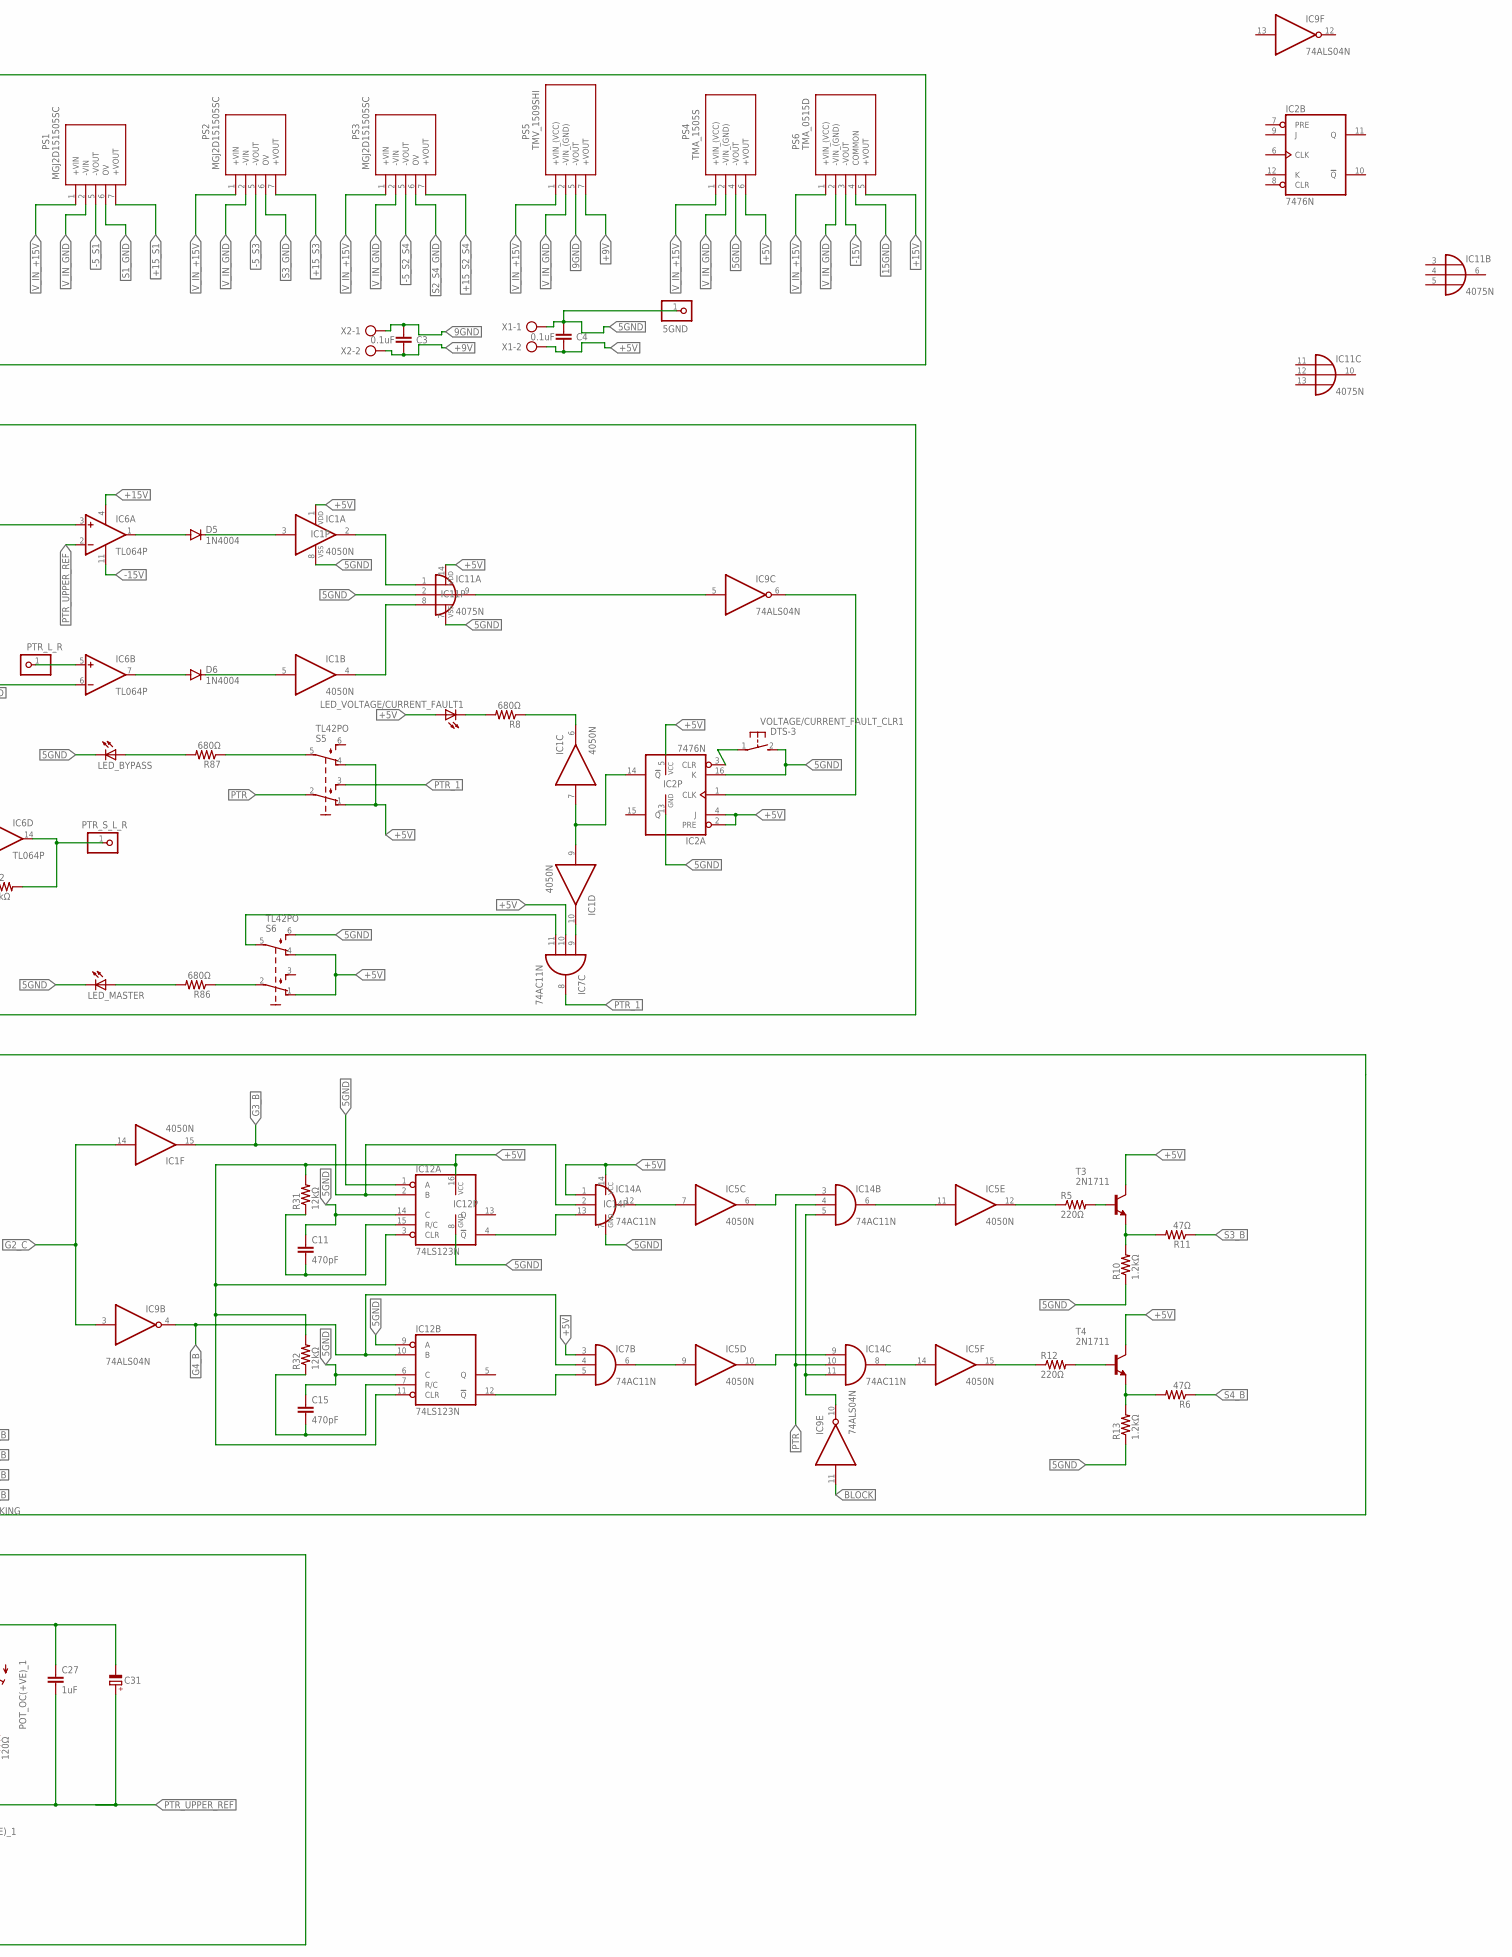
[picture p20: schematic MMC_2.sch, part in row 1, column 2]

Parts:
5GND, 15GND: PINHD-1X1; 1X01
C1, C2: MOUNT-PAD-ROUND; 6-PAD
C1_470µF, C2_470µF, C3_470µF, C4_470µF: MAL215746471E3; CAP_2157_30X50_VIS
C3, C4, C12, C13, C14, C16, C17, C18, C19, C20, C21, C23, C24, C25, C26: 0.1uF; C025-025X050
C5, C10, C11, C15: 470pF; C025-025X050
C6, C7, C8, C9: 10nF; C150-054X183
C22, C27, C29: 1uF; C025-025X050
C28, C30, C31: CPOL-EUE2-4; E2-4
D5, D6: 1N4004; DO41-10
D7, D8, D9, D10, D11, D12, D13, D14: ZENER-DIODEDO35Z10; DO35Z10
D15, D16, D17, D18: BYW80; TO220ACS
FOD1, FOD3, FOD4, FOD6: FOD3182; DIL08
GATE_SIGNALS_BLANKING: PINHD-1X4; 1X04
GATE_SIGNAL_FROM_DSP: PINHD-1X3; 1X03
H1, H2, H3: MOUNT-PAD-ROUND; 6-PAD
HS1, HS2, HS3, HS4: 6396BG; HSINK_6396BG
IC1, IC3, IC5: 4050N; DIL16
IC2: 7476N; DIL16
IC4, IC7, IC14: 74AC11N; DIL14
IC6: TL064P; DIL14
IC8: LV25-P
IC9: 74ALS04N; DIL14
IC10, IC12: 74LS123N; DIL16
IC11: 4075N; DIL14
LED_BYPASS: LED3MM
LED_MASTER: LED3MM
LED_VOLTAGE/CURRENT_FAULT1: LED3MM
LM317_I(+VE)_1, LM317_I(+VE)_2: LM317TS; 317TS
POT_OC(+VE)_1, POT_OC(+VE)_2: R-TRIMMT93YA; RTRIMT93YA
PS1, PS2, PS3: MGJ2D151505SC
PS4: TMA_1505S; TMA0505S
PS5: TMV_1509SHI; TMV1512SHI
PS6: TMA_0515D; TMA0515D
PTR_L: PINHD-1X1; 1X01
PTR_L_R: PINHD-1X1; 1X01
PTR_L_UNSCALED: PINHD-1X1; 1X01
PTR_S_L_R: PINHD-1X1; 1X01
PTR_U: PINHD-1X1; 1X01
Q1, Q2, Q3, Q4: TIP35-V; TO247-V
R1, R2, R3, R4: 2kΩ; 0414/15
R5, R12, R17, R18, R19, R20, R37, R39: 220Ω; 0207/10
R6, R11, R38, R53: 47Ω; 0207/10
R7, R14, R15, R16, R23, R28, R33, R34: 18Ω; 0207/10
R8, R86, R87: 680Ω; 0207/10
R9: 300 R; RTRIMT93YA
R10, R13, R36, R52: 1.2kΩ; 0207/10
R21, R41, R42: 10kΩ; 0207/10
R22, R51: 120Ω; 0207/10
R24, R25, R26, R27: 1kΩ; 0207/10
R28_10KΩ: SBCHE610KJ
R29, R30, R31, R32: 12kΩ; 0207/10
R35: 75kΩ; 0411/15
R40: 2kΩ; 0207/10
S1, S2, S3, S4, S11, S22, S33, S44: PINHD-1X2; 1X02
S5, S6: TL42PO; TL4XPO
T1, T2, T3, T4: 2N1711; TO39
VOLTAGE/CURRENT_FAULT_CLR1: DTS-3
V_SM: PINHD-1X1; 1X01
X1, X2, X3: AK300/2
X4: AK300/3

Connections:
5GND: 5GND.1, C4.2, C5.1, C10.1, C11.1, C15.1, IC1.8 (VSS), IC2.13 (GND), IC2.16 (K), IC3.8 (VSS), IC4.7 (GND), IC5.8 (VSS), IC7.7 (GND), IC9.7 (GND), IC10.1 (A), IC10.6 (C), IC10.8 (GND), IC10.9 (A), IC10.14 (C), IC11.2 (I1), IC11.7 (VSS), IC12.1 (A), IC12.6 (C), IC12.8 (GND), IC12.9 (A), IC12.14 (C), IC14.7 (GND), LED_BYPASS.K (C), LED_MASTER.K (C), PS4.4 (-VOUT), R10.1, R13.1, R17.1, R18.1, R19.1, R20.1, R36.1, R52.1, S6.6 (S1), VOLTAGE/CURRENT_FAULT_CLR1.2, X1.1
9GND: C3.2, C21.1, C22.1, C26.1, C27.1, C30.-, C31.-, POT_OC(+VE)_1.2 (S), POT_OC(+VE)_2.2 (S), PS5.5 (-VOUT), X2.1
15GND: 15GND.1, C24.2, C25.2, C28.-, C29.2, IC6.10 (+IN), IC6.12 (+IN), PS6.4 (COMMON), R9.3 (A), X4.2
+5V: C4.1, IC1.1 (VDD), IC2.2 (PRE), IC2.4 (J), IC2.5 (VCC), IC3.1 (VDD), IC4.1 (I0), IC4.3 (I0), IC4.14 (VCC), IC5.1 (VDD), IC7.3 (I0), IC7.10 (I1), IC7.14 (VCC), IC9.14 (VCC), IC10.3 (CLR), IC10.11 (CLR), IC10.16 (VCC), IC11.14 (VDD), IC12.3 (CLR), IC12.11 (CLR), IC12.16 (VCC), IC14.1 (I0), IC14.14 (VCC), LED_VOLTAGE/CURRENT_FAULT1.A, PS4.6 (+VOUT), R29.2, R30.2, R31.2, R32.2, S5.1 (O), S5.4 (O1), S6.1 (O), S6.4 (O1), T1.3 (C), T2.3 (C), T3.3 (C), T4.3 (C), X1.2
+9V: C3.1, C21.2, C26.2, LM317_I(+VE)_1.3 (IN), LM317_I(+VE)_2.3 (IN), PS5.7 (+VOUT), X2.2
+15V: C24.1, IC6.4 (V+), IC8.4 (+), PS6.5 (+VOUT), X4.3
+15_S1: C12.1, FOD1.8 (VCC), PS1.7 (+VOUT)
+15_S2_S4: C13.1, C16.1, FOD3.8 (VCC), FOD6.8 (VCC), PS3.7 (+VOUT)
+15_S3: C14.1, FOD4.8 (VCC), PS2.7 (+VOUT)
-5_S1: C17.2, FOD1.5 (GND), PS1.5 (-VOUT)
-5_S2_S4: C19.1, C20.1, FOD3.5 (GND), FOD6.5 (GND), PS3.5 (-VOUT)
-5_S3: C18.1, FOD4.5 (GND), PS2.5 (-VOUT)
-15V: C25.1, IC6.11 (V-), IC8.5 (-), PS6.3 (-VOUT), X4.1
AA: D12.C, Q1.1 (B), R7.1, R26.1, R33.1
BLOCK: GATE_SIGNAL_FROM_DSP.3, IC9.9 (I), IC9.11 (I)
G1_B: GATE_SIGNALS_BLANKING.1, IC1.12 (O), IC4.2 (I1), IC10.2 (B)
G1_C: GATE_SIGNAL_FROM_DSP.1, IC1.11 (I), IC9.1 (I)
G2_B: GATE_SIGNALS_BLANKING.2, IC4.4 (I1), IC9.2 (O), IC10.10 (B)
G2_C: GATE_SIGNAL_FROM_DSP.2, IC1.14 (I), IC9.3 (I)
G3_B: GATE_SIGNALS_BLANKING.3, IC1.15 (O), IC12.2 (B), IC14.2 (I1)
G4_B: GATE_SIGNALS_BLANKING.4, IC7.4 (I1), IC9.4 (O), IC12.10 (B)
GND(5): FOD3.3 (C), R19.2
unnamed: FOD1.2 (A), IC3.2 (O)
unnamed: D8.C, Q4.1 (B), R16.2, R24.1, R28.2
unnamed: D10.C, Q3.1 (B), R15.2, R23.2, R25.1
unnamed: IC7.11 (I2), S6.5 (P1)
unnamed: D5.A, IC6.1 (OUT)
unnamed: IC1.10 (O), IC7.9 (I0)
unnamed: C9.2, D17.A, R3.1
unnamed: IC12.4 (!Q), IC14.13 (I2)
unnamed: IC5.7 (I), IC14.12 (O)
unnamed: IC5.6 (O), IC14.3 (I0)
unnamed: IC5.11 (I), IC14.6 (O)
unnamed: IC5.12 (O), R5.1
unnamed: R5.2, T3.2 (B)
unnamed: C8.1, D18.C, R4.2
unnamed: R10.2, R11.2, T3.1 (E)
unnamed: IC5.15 (O), R12.1
unnamed: C6.1, D15.C, R2.2
unnamed: FOD3.2 (A), IC3.4 (O)
unnamed: FOD4.2 (A), IC3.6 (O)
unnamed: FOD6.2 (A), IC3.10 (O)
unnamed: FOD1.3 (C), R17.2
unnamed: FOD4.3 (C), R18.2
unnamed: FOD6.3 (C), R20.2
unnamed: R12.2, T4.2 (B)
unnamed: R6.2, R13.2, T4.1 (E)
unnamed: D5.C, IC1.3 (I)
unnamed: IC5.5 (I), IC7.12 (O)
unnamed: IC4.11 (I2), IC7.13 (I2), IC9.8 (O)
unnamed: IC7.5 (I2), IC12.12 (!Q)
unnamed: IC5.9 (I), IC7.6 (O)
unnamed: IC5.10 (O), IC14.9 (I0)
unnamed: IC9.10 (O), IC14.5 (I2), IC14.11 (I2)
unnamed: IC5.14 (I), IC14.8 (O)
unnamed: IC6.5 (+IN), PTR_L_R.1
unnamed: IC8.2 (+HT), R35.2
unnamed: LM317_I(+VE)_1.1 (ADJ), POT_OC(+VE)_1.1 (E), R51.2
unnamed: C7.2, D16.A, R1.1
unnamed: IC6.9 (-IN), R21.1, R40.1
unnamed: IC6.8 (OUT), R40.2, R41.1
unnamed: D7.A, D8.A
unnamed: D9.A, D10.A
unnamed: D11.A, D12.A
unnamed: D13.A, D14.A
unnamed: IC9.5 (I), IC11.9 (O)
unnamed: IC6.13 (-IN), R41.2, R42.1
unnamed: IC1.2 (O), IC11.1 (I0)
unnamed: D6.A, IC6.7 (OUT)
unnamed: IC1.4 (O), IC11.8 (I2)
unnamed: D6.C, IC1.5 (I)
unnamed: LM317_I(+VE)_2.1 (ADJ), POT_OC(+VE)_2.1 (E), R22.2
unnamed: IC2.1 (CLK), IC9.6 (O)
unnamed: IC1.6 (O), R8.1
unnamed: LED_VOLTAGE/CURRENT_FAULT1.K (C), R8.2
unnamed: IC2.3 (CLR), VOLTAGE/CURRENT_FAULT_CLR1.1
unnamed: C5.2, IC10.15 (R/C), R29.1
unnamed: C10.2, IC10.7 (R/C), R30.1
unnamed: C11.2, IC12.15 (R/C), R31.1
unnamed: IC4.13 (I2), IC10.4 (!Q)
unnamed: IC4.12 (O), IC5.3 (I)
unnamed: IC5.2 (O), IC7.1 (I0)
unnamed: IC5.4 (O), R37.1
unnamed: R37.2, T1.2 (B)
unnamed: R36.2, R38.2, T1.1 (E)
unnamed: IC3.15 (O), R39.1
unnamed: R39.2, T2.2 (B)
unnamed: R52.2, R53.2, T2.1 (E)
unnamed: IC4.5 (I2), IC10.12 (!Q)
unnamed: IC3.11 (I), IC4.6 (O)
unnamed: IC3.12 (O), IC4.9 (I0)
unnamed: IC3.14 (I), IC4.8 (O)
unnamed: C15.2, IC12.7 (R/C), R32.1
unnamed: R86.1, S6.2
unnamed: LED_MASTER.A, R86.2
unnamed: R87.1, S5.5 (P1)
unnamed: LED_BYPASS.A, R87.2
PTR: IC4.10 (I1), IC7.2 (I1), IC14.4 (I1), IC14.10 (I1), S5.2
PTR_1: IC7.8 (O), S5.3 (S)
PTR_LOWER_REF: C22.2, C30.+, LM317_I(+VE)_2.2 (OUT), PTR_L_UNSCALED.1, R21.2, R22.1
PTR_S_L_R: IC6.14 (OUT), PTR_L.1, PTR_S_L_R.1, R42.2
PTR_UPPER_REF: C27.2, C31.+, IC6.2 (-IN), LM317_I(+VE)_1.2 (OUT), PTR_U.1, R51.1
Q_BAR: IC1.7 (I), IC1.9 (I), IC2.14 (!Q)
S1_B: IC3.3 (I), R38.1
S1_G: FOD1.6 (VE), FOD1.7 (VO), R7.2, R33.2, S1.1, S11.1
S1_GND: C12.2, C17.1, D11.C, D15.A, D16.C, H1.B5,5, PS1.6 (OV), Q1.3 (E), Q2.2 (C), R26.2, S1.2, S11.2
S2_B: IC3.5 (I), R53.1
S2_G: FOD3.6 (VE), FOD3.7 (VO), R14.2, R34.2, S2.1, S22.1
S2_S4_GND: C1_470µF.1, C2.B5,5, C2_470µF.1, C3_470µF.1, C4_470µF.1, C6.2, C8.2, C13.2, C16.2, C19.2, C20.2, D7.C, D13.C, H3.B5,5, IC8.1 (-HT), PS3.6 (OV), Q2.3 (E), Q4.3 (E), R1.2, R3.2, R24.2, R27.2, R28_10KΩ.1, S2.2, S4.2, S22.2, S44.2
S3_B: IC3.7 (I), R11.1
S3_G: FOD4.6 (VE), FOD4.7 (VO), R15.1, R23.1, S3.1, S33.1
S3_GND: C14.2, C18.2, D9.C, D17.C, D18.A, H2.B5,5, PS2.6 (OV), Q3.3 (E), Q4.2 (C), R25.2, S3.2, S33.2
S4_B: IC3.9 (I), R6.1
S4_G: FOD6.6 (VE), FOD6.7 (VO), R16.1, R28.1, S4.1, S44.1
S222: D14.C, Q2.1 (B), R14.1, R27.1, R34.1
V_IN_+15V: C23.2, PS1.1 (+VIN), PS2.1 (+VIN), PS3.1 (+VIN), PS4.1 (+VIN_(VCC)), PS5.1 (+VIN_(VCC)), PS6.1 (+VIN_(VCC)), X3.1
V_IN_GND: C23.1, PS1.2 (-VIN), PS2.2 (-VIN), PS3.2 (-VIN), PS4.2 (-VIN_(GND)), PS5.2 (-VIN_(GND)), PS6.2 (-VIN_(GND)), X3.2
V_SM: C1.B5,5, C1_470µF.2, C2_470µF.2, C3_470µF.2, C4_470µF.2, C7.1, C9.1, Q1.2 (C), Q3.2 (C), R2.1, R4.1, R28_10KΩ.2, R35.1
V_SM_VS: C28.+, C29.1, IC6.3 (+IN), IC6.6 (-IN), IC8.3 (M), R9.2 (S), V_SM.1

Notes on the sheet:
5.Power_supplies
1.Power_circuit
2. Driver_Circuit
3. Protection_Circuit
4. Blanking_Circuit
6. Voltage_sensing_Circuit
7. Reference_Signal_Generator
Capacitor terminal

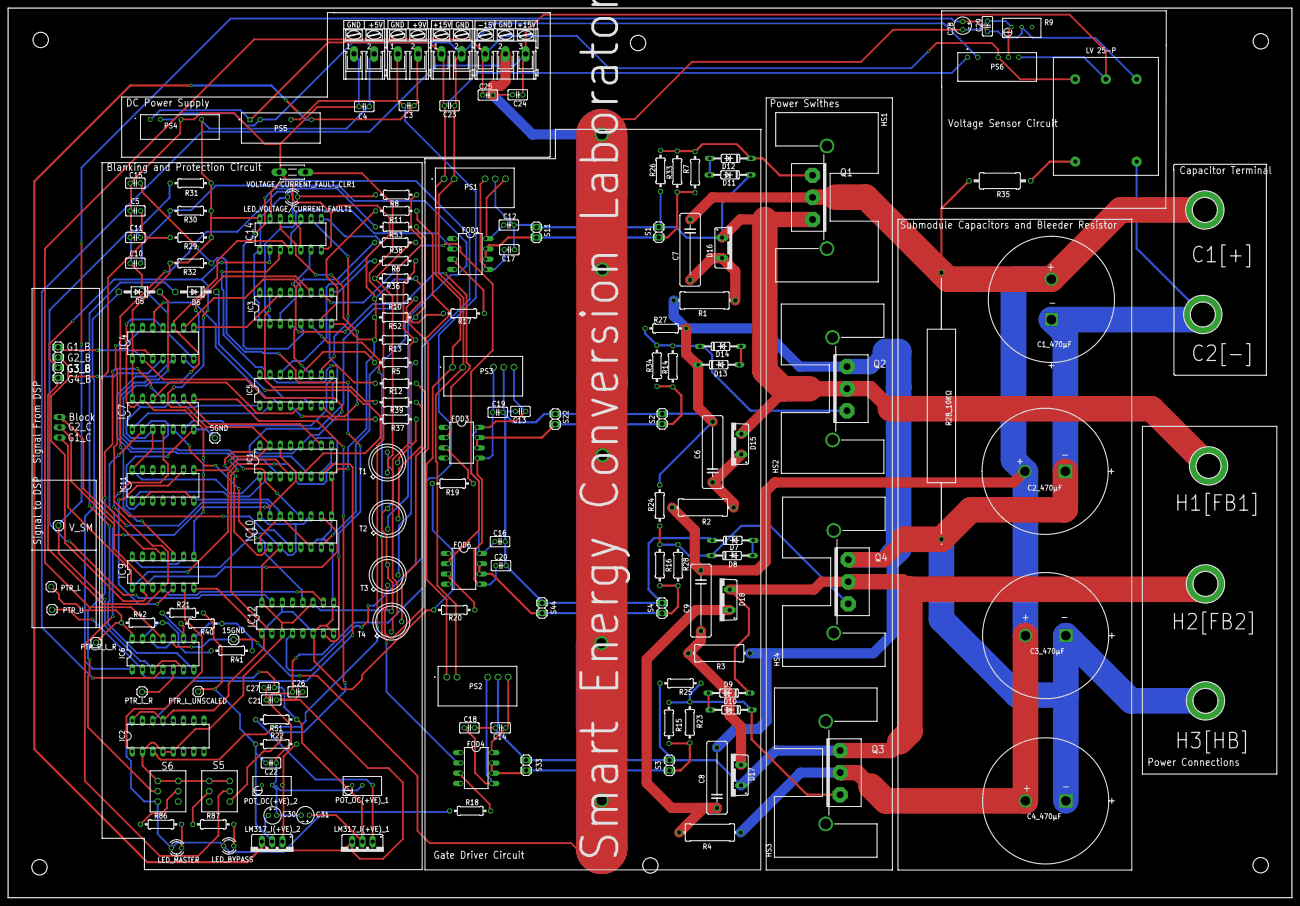
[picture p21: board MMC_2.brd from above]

Board: 2 copper layers, 317.9 x 220.2 mm, 167 parts (1 on the bottom side), 119 nets.

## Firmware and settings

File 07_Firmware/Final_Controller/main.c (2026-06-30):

//#############################################################################
//
// FILE:    main.c
//
// TITLE:   Synchronous Buck Converter - Cascaded Digital Controller
//          TI LaunchXL-F28379D | CPU1 | Driverlib | C2000Ware
//
// DESCRIPTION:
//   This firmware implements a cascaded PI control architecture for a
//   synchronous buck converter with the following specs:
//
//     Vin  = 24V     Vout = 12V     Fsw  = 100kHz
//     L    = 50uH    C    = 12.5uF  Rload = 12 Ohm
//
// CASCADED CONTROL ARCHITECTURE:
//
//   Vref -->[+]-->[ Voltage PI ]-->[ Iref ]-->[+]-->[ Current PI ]-->[ Duty ]
//            [-]                               [-]
//            |                                 |
//           Vout (ADC)                        Iout (ADC)
//
//   Outer Loop (Voltage): Slower. Compares Vout to Vref, outputs Iref.
//   Inner Loop (Current): Faster. Compares Iout to Iref, outputs duty cycle.
//   Both loops execute inside the ADC ISR at 100kHz.
//
// SIMULINK MAPPING:
//   Simulink Voltage PI Block   → voltageController in controller.c
//   Simulink Current PI Block   → currentController in controller.c
//   Simulink PWM Generator      → epwm.c (EPWM1, up-down mode, CMPA)
//   Simulink ADC Block          → adc.c (ADCA/ADCB, ePWM triggered)
//   Simulink Scope/Output       → Watch Window (g_vOut, g_iOut, g_duty)
//
//#############################################################################

#include "driverlib.h"
#include "device.h"
#include "epwm.h"
#include "adc.h"
#include "controller.h"
#include "interrupts.h"

//
// Main
//
void main(void)
{
    //
    // Step 1: Device Initialization
    // Configures system clocks (200MHz SYSCLK), watchdog, and peripheral clocks.
    // Must always be the first call.
    //
    Device_init();

    //
    // Step 2: GPIO Initialization
    // Unlocks all GPIO pins and sets default states.
    // Required before any GPIO_setPinConfig() calls.
    //
    Device_initGPIO();

    //
    // Step 3: Interrupt Module Initialization
    // Resets the PIE (Peripheral Interrupt Expansion) controller.
    // Clears all CPU interrupt flags.
    // Disables all interrupts during configuration.
    //
    Interrupt_initModule();

    //
    // Step 4: PIE Vector Table Initialization
    // Loads default shell ISR addresses into all 96 PIE interrupt vectors.
    // Our actual ISR (ADC_ISR) will overwrite the relevant vector below.
    //
    Interrupt_initVectorTable();

    //
    // Step 5: Register ADC ISR into PIE Vector Table
    // INT_ADCA1 = PIE Group 1, Vector 1 = ADCA End-of-Conversion interrupt
    // This tells the CPU where to jump when ADCA conversion completes.
    //
    Interrupt_register(INT_ADCA1, &ADC_ISR);

    //
    // Step 6: ePWM Configuration
    // Configures EPWM1 for 100kHz switching, up-down count mode,
    // and ADC trigger generation at counter zero.
    // GPIO0 = EPWM1A (High Side), GPIO1 = EPWM1B (Low Side, complementary)
    //
    EPWM_configure();

    //
    // Step 7: ADC Configuration
    // Configures ADCA for voltage feedback (ADCINA0)
    // Configures ADCB for current feedback (ADCINB0)
    // Both triggered by EPWM1 SOCA at counter zero (100kHz sampling rate)
    //
    ADC_configure();

    //
    // Step 8: Controller Initialization
    // Zeros all PI state variables (integrators, previous errors)
    // Sets Vref = 12V target output voltage
    //
    Controller_init();

    //
    // Step 9: Enable ADC Interrupt
    // Enables ADCA EOC (End of Conversion) interrupt in PIE Group 1
    //
    Interrupt_enable(INT_ADCA1);

    //
    // Step 10: Enable Global Interrupts
    // EINT = Enable INTerrupts (clears INTM bit in ST1 register)
    // ERTM = Enable Real-Time Mode (allows Watch Window updates while running)
    //
    EINT;
    ERTM;

    //
    // Infinite background loop.
    // All control work happens in ADC_ISR at 100kHz.
    // CPU is otherwise idle.
    //
    for(;;)
    {
        NOP;
    }
}

//
// End of File
//

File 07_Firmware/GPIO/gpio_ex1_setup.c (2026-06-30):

//#############################################################################
//
// FILE:    gpio_ex1_setup.c
//
// TITLE:   Device GPIO Setup
//
//! \addtogroup driver_example_list
//! <h1> Device GPIO Setup </h1>
//!
//! Configures the device GPIO into two different configurations
//! This code is verbose to illustrate how the GPIO could be setup.
//! In a real application, lines of code can be combined for improved
//! code size and efficiency.
//!
//! This example only sets-up the GPIO. Nothing is actually done with
//! the pins after setup.
//!
//! \b In \b general: \n
//!  - All pullup resistors are enabled.  For ePWMs this may not be desired.
//!  - Input qual for communication ports (CAN, SPI, SCI, I2C) is asynchronous
//!  - Input qual for Trip pins (TZ) is asynchronous
//!  - Input qual for eCAP and eQEP signals is synch to SYSCLKOUT
//!  - Input qual for some I/O's and __interrupts may have a sampling window
//
//#############################################################################
//
// 
// $Copyright:
// Copyright (C) 2013-2024 Texas Instruments Incorporated - http://www.ti.com/
//
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
//   Redistributions of source code must retain the above copyright 
//   notice, this list of conditions and the following disclaimer.
// 
//   Redistributions in binary form must reproduce the above copyright
//   notice, this list of conditions and the following disclaimer in the 
//   documentation and/or other materials provided with the   
//   distribution.
// 
//   Neither the name of Texas Instruments Incorporated nor the names of
//   its contributors may be used to endorse or promote products derived
//   from this software without specific prior written permission.
// 
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
//
// Included Files
//
#include "driverlib.h"
#include "device.h"

//
// Defines
// Select the example to compile in.  Only one example should be set as 1
// the rest should be set as 0.
//
#define EXAMPLE1 1  // Basic pinout configuration example
#define EXAMPLE2 0  // Communication pinout example

//
// Function Prototypes
//
void setup1GPIO(void);
void setup2GPIO(void);

//
// Main
//
void main(void)
{
    //
    // Initializes system control, device clock, and peripherals
    //
    Device_init();

    //
    // Initializes PIE and clear PIE registers. Disables CPU interrupts.
    // and clear all CPU interrupt flags.
    //
    Interrupt_initModule();

    //
    // Initialize the PIE vector table with pointers to the shell interrupt
    // Service Routines (ISR).
    //
    Interrupt_initVectorTable();

#if EXAMPLE1

    //
    // This example is a basic pinout
    //
    setup1GPIO();

// Configure onboard LED1 (GPIO31) as output, start LOW
GPIO_setPadConfig(31, GPIO_PIN_TYPE_STD);
GPIO_writePin(31, 1);
GPIO_setPinConfig(GPIO_31_GPIO31);
GPIO_setDirectionMode(31, GPIO_DIR_MODE_OUT);

#endif  // - EXAMPLE1

#if EXAMPLE2

    //
    // This example is a communications pinout
    //
    setup2GPIO();

#endif

}

//
// setup1GPIO - Is an example that demonstrates the basic pinout
//
void
setup1GPIO(void)
{
    //
    // Example 1: Basic Pinout.
    // This basic pinout includes:
    // PWM1-3, ECAP1, ECAP2, TZ1-TZ4, SPI-A, EQEP1, SCI-A, I2C
    // and a number of I/O pins
    // These can be combined into single statements for improved
    // code efficiency.
    //

    //
    // Enable PWM1-3 on GPIO0-GPIO5
    //
    GPIO_setPadConfig(0, GPIO_PIN_TYPE_PULLUP);     // Enable pullup on GPIO0
    GPIO_setPadConfig(1, GPIO_PIN_TYPE_PULLUP);     // Enable pullup on GPIO1
    GPIO_setPadConfig(2, GPIO_PIN_TYPE_PULLUP);     // Enable pullup on GPIO2
    GPIO_setPadConfig(3, GPIO_PIN_TYPE_PULLUP);     // Enable pullup on GPIO3
    GPIO_setPadConfig(4, GPIO_PIN_TYPE_PULLUP);     // Enable pullup on GPIO4
    GPIO_setPadConfig(5, GPIO_PIN_TYPE_PULLUP);     // Enable pullup on GPIO5
    GPIO_setPinConfig(GPIO_0_EPWM1A);               // GPIO0 = PWM1A
    GPIO_setPinConfig(GPIO_1_EPWM1B);               // GPIO1 = PWM1B
    GPIO_setPinConfig(GPIO_2_EPWM2A);               // GPIO2 = PWM2A
    GPIO_setPinConfig(GPIO_3_EPWM2B);               // GPIO3 = PWM2B
    GPIO_setPinConfig(GPIO_4_EPWM3A);               // GPIO4 = PWM3A
    GPIO_setPinConfig(GPIO_5_EPWM3B);               // GPIO5 = PWM3B

    //
    // Enable a GPIO output on GPIO6, set it high
    //
    GPIO_setPadConfig(6, GPIO_PIN_TYPE_PULLUP);     // Enable pullup on GPIO6
    GPIO_writePin(6, 1);                            // Load output latch
    GPIO_setPinConfig(GPIO_6_GPIO6);                // GPIO6 = GPIO6
    GPIO_setDirectionMode(6, GPIO_DIR_MODE_OUT);    // GPIO6 = output

    //
    // Enable eCAP1 on GPIO7
    //
    GPIO_setPadConfig(7, GPIO_PIN_TYPE_PULLUP);     // Enable pullup on GPIO7
    GPIO_setQualificationMode(7, GPIO_QUAL_SYNC);   // Synch to SYSCLKOUT
    XBAR_setInputPin(XBAR_INPUT7, 7);               // GPIO7 = ECAP1

    //
    // Enable GPIO outputs on GPIO8 - GPIO11, set it high
    //
    GPIO_setPadConfig(8, GPIO_PIN_TYPE_PULLUP);     // Enable pullup on GPIO8
    GPIO_writePin(8, 1);                            // Load output latch
    GPIO_setPinConfig(GPIO_8_GPIO8);                // GPIO8 = GPIO8
    GPIO_setDirectionMode(8, GPIO_DIR_MODE_OUT);    // GPIO8 = output

    GPIO_setPadConfig(9, GPIO_PIN_TYPE_PULLUP);     // Enable pullup on GPIO9
    GPIO_writePin(9, 1);                            // Load output latch
    GPIO_setPinConfig(GPIO_9_GPIO9);                // GPIO9 = GPIO9
    GPIO_setDirectionMode(9, GPIO_DIR_MODE_OUT);    // GPIO9 = output

    GPIO_setPadConfig(10, GPIO_PIN_TYPE_PULLUP);    // Enable pullup on GPIO10
    GPIO_writePin(10, 1);                           // Load output latch
    GPIO_setPinConfig(GPIO_10_GPIO10);              // GPIO10 = GPIO10
    GPIO_setDirectionMode(10, GPIO_DIR_MODE_OUT);   // GPIO10 = output

    GPIO_setPadConfig(11, GPIO_PIN_TYPE_PULLUP);    // Enable pullup on GPIO11
    GPIO_writePin(11, 1);                           // Load output latch
    GPIO_setPinConfig(GPIO_11_GPIO11);              // GPIO11 = GPIO11
    GPIO_setDirectionMode(11, GPIO_DIR_MODE_OUT);   // GPIO11 = output

    //
    // Enable Trip Zone inputs on GPIO12 - GPIO14
    //
    GPIO_setPadConfig(12, GPIO_PIN_TYPE_PULLUP);    // Enable pullup on GPIO12
    GPIO_setPadConfig(13, GPIO_PIN_TYPE_PULLUP);    // Enable pullup on GPIO13
    GPIO_setPadConfig(14, GPIO_PIN_TYPE_PULLUP);    // Enable pullup on GPIO14
    GPIO_setQualificationMode(12, GPIO_QUAL_ASYNC); // asynch input
    GPIO_setQualificationMode(13, GPIO_QUAL_ASYNC); // asynch input
    GPIO_setQualificationMode(14, GPIO_QUAL_ASYNC); // asynch input
    XBAR_setInputPin(XBAR_INPUT1, 12);              // GPIO12 = TZ1
    XBAR_setInputPin(XBAR_INPUT2, 13);              // GPIO13 = TZ2
    XBAR_setInputPin(XBAR_INPUT3, 14);              // GPIO14 = TZ3
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

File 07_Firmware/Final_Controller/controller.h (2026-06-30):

//#############################################################################
//
// FILE:    controller.h
//
// TITLE:   Cascaded PI Controller Header - Synchronous Buck Converter
//
// CONTROL ARCHITECTURE:
//
//          Vref
//           |
//          [+]
//           |  error_v
//    Vout--[-]
//           |
//    [ Voltage PI ] ──── Iref (current reference)
//           |
//          [+]
//           |  error_i
//    Iout--[-]
//           |
//    [ Current PI ] ──── duty (0.0 to 1.0)
//           |
//      [ EPWM1 CMPA ]
//
// SIMULINK MAPPING:
//   Voltage PI block → voltagePI struct + PI_update() call
//   Current PI block → currentPI struct + PI_update() call
//   Anti-windup clamp → PI_update() integrator clamp
//   Saturation block  → duty clamp in EPWM_setDutyCycle()
//
//#############################################################################

#ifndef CONTROLLER_H
#define CONTROLLER_H

#include "driverlib.h"
#include "device.h"

//
// System Reference Values
//
#define VREF                12.0f       // Target output voltage (V)
#define IREF_MAX            2.0f        // Max current reference from voltage loop (A)
#define IREF_MIN            0.0f        // Min current reference (no negative current)

//
// Voltage PI Gains
// Tuned for: Vout loop bandwidth ~1kHz (much slower than 100kHz switching)
// Start conservative — increase Kp until oscillation, then back off 50%
// These values are initial estimates; tune on hardware with scope
//
#define VOLTAGE_KP          0.05f       // Proportional gain
#define VOLTAGE_KI          0.001f      // Integral gain
#define VOLTAGE_IMAX        2.0f        // Integrator anti-windup clamp (A)
#define VOLTAGE_IMIN        0.0f        // Integrator min clamp

//
// Current PI Gains
// Tuned for: Iout loop bandwidth ~10kHz (10x faster than voltage loop)
// Inner loop must be significantly faster than outer loop for stability
//
#define CURRENT_KP          0.1f        // Proportional gain
#define CURRENT_KI          0.01f       // Integral gain
#define CURRENT_IMAX        0.95f       // Integrator max clamp (duty cycle max)
#define CURRENT_IMIN        0.05f       // Integrator min clamp (duty cycle min)

//
// Sampling Period
// Ts = 1/Fsw = 1/100kHz = 10us
// Used in discrete integrator: integral += error * Ki * Ts
//
#define TS                  0.00001f    // 10 microseconds

//
// PI Controller Structure
// One instance per control loop (voltage and current)
//
typedef struct
{
    float32_t kp;           // Proportional gain
    float32_t ki;           // Integral gain
    float32_t integrator;   // Integrator state (accumulates over time)
    float32_t outMax;       // Output upper clamp (anti-windup)
    float32_t outMin;       // Output lower clamp (anti-windup)
    float32_t output;       // Controller output
} PI_Controller;

//
// Global Controller Instances
//
extern PI_Controller voltagePI;     // Outer voltage loop
extern PI_Controller currentPI;     // Inner current loop

//
// Global Control Signals (visible in Watch Window)
//
extern volatile float32_t g_vref;       // Voltage reference (V)
extern volatile float32_t g_iref;       // Current reference from voltage loop (A)
extern volatile float32_t g_duty;       // Duty cycle output (0.0 to 1.0)
extern volatile float32_t g_error_v;    // Voltage error (debug)
extern volatile float32_t g_error_i;    // Current error (debug)

//
// Function Prototypes
//
void Controller_init(void);
float32_t PI_update(PI_Controller *pi, float32_t reference, float32_t feedback);

#endif // CONTROLLER_H

//
// End of File
//
